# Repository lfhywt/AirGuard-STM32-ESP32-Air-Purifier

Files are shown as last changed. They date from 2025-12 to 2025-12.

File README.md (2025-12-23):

English version: [README_EN.md](README_EN.md)

# AirGuard-STM32-ESP32-Air-Purifier

# AirGuard

**AirGuard** 是一款 **成品级智能空气净化器系统**，集成空气质量检测、风扇控制、本地屏幕交互以及云端 App 远程控制。

本项目从 **硬件设计到软件实现全部由本人独立完成**，包括：

- 原理图设计  
- PCB 设计与打板  
- 元器件焊接  
- 3D 外壳建模（部分）  
- STM32 / ESP32 嵌入式代码开发  
  

   

   

---

## 项目特点

- STM32 + ESP32 **双 MCU 架构**
- 空气质量实时监测  
  - PM2.5 / PM10  
  - VOC  
  - 温湿度  
- 本地串口屏交互（Nextion）
- Blinker App 云端远程控制与状态同步
- 自定义通信协议与状态同步机制
- 3D 打印外壳，完整成品形态  

> 外壳模板参考并感谢原作者：  
> **tatzhao**  
> https://oshwhub.com/tatzhao/smart-colorful-air-purifier-spark-plan

---

## 实现步骤

### 1. PCB 打板

- 根据 Gerber 文件在 **嘉立创** 打板  
- 板子尺寸：**100mm × 40mm**
- 可使用嘉立创的免费打板券

---

### 2. 元器件采购

- 根据 BOM 表购买元器件  
- **务必逐项核对型号与参数**

---

### 3. 焊接注意事项

⚠️ **非常重要**

- **需要去掉 R3 电阻**  
  否则 STM32 无法正常工作
- **需要去掉 CH340**  
  否则会与串口屏冲突，导致屏幕无法正确发送指令

---

### 4. STM32 固件烧录

#### 串口烧录（FLYMCU）

- 使用 **PA9 / PA10**
- BOOT 配置：
  - BOOT0 = 高电平
  - BOOT1 = 低电平（VCC → BOOT0，GND → BOOT1）
- 烧录完成后：
  - BOOT0 = 低电平
  - BOOT1 = 低电平

#### ST-Link 烧录

- BOOT0 = 低电平
- BOOT1 = 低电平
- 已经引出对应 SWD 引脚

---

### 5. ESP32 固件烧录

- 开发环境：**Arduino IDE**
- 目标型号：**ESP32-S3 Dev Module**
- 使用串口烧录：
  - RX ↔ TX
  - TX ↔ RX

#### 下载模式进入方式

1. 按住 **SW1（复位）**
2. 按住 **SW2（IO 拉低）**
3. 松开 SW1
4. 松开 SW2
5. 上传固件
6. 烧录完成后复位

#### 注意事项

- 使用 **Blinker（点灯科技）SDK**
- 通信协议：**MQTT**
- **不建议使用 ESP8266**
- 若 ESP32 内存不足：
  - 在 Arduino IDE 中调整 `Partition Scheme`
  - 建议选择 **App > 1MB**
   

---

### 6. 3D 外壳

- 基于原作者提供的 3D 模型
- 根据自身需求进行二次修改与定制
- 3D 打印后组装成完整成品

---

### 7. 显示屏

- 型号：**淘晶驰 T1 系列 4.3 英寸串口触摸屏**
- 可淘宝购买或自行更换其他型号

⚠️ **注意**

- 使用串口屏时 **不要焊接 CH340**
- 否则会干扰 STM32 与屏幕通信

---

### 8. 风扇

- 型号：**利民 TL-B12W EXTREM 12cm**
- 风量充足，噪音较低，实际使用效果良好

---

### 9. 空气传感器模块

- 使用 **康福尔集成传感器模块**
- 通过串口接收协议帧并解析数据
- 相比自研传感器方案，成本更低、实现更简单

---

## ⚠️ 重要声明

- **本项目无任何防呆保护**
- 接线务必确认正确  
- 错误接线可能导致器件损坏或财产损失  

❗ **本项目仅用于学习与开源交流，严禁商用**

---

## License

本项目遵循开源协议，仅供学习研究使用。

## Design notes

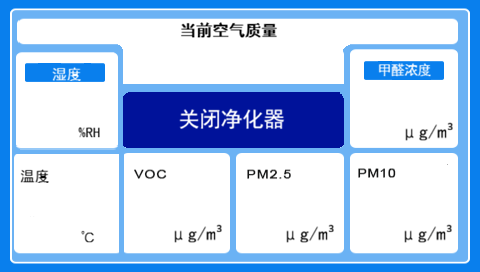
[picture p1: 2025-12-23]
屏幕HMI/关机.png

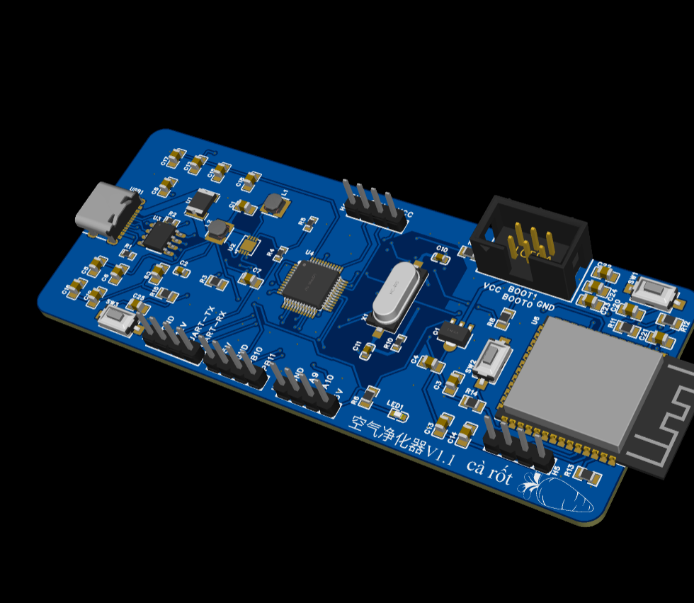
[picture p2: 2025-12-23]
主控板/主控板3D图.png

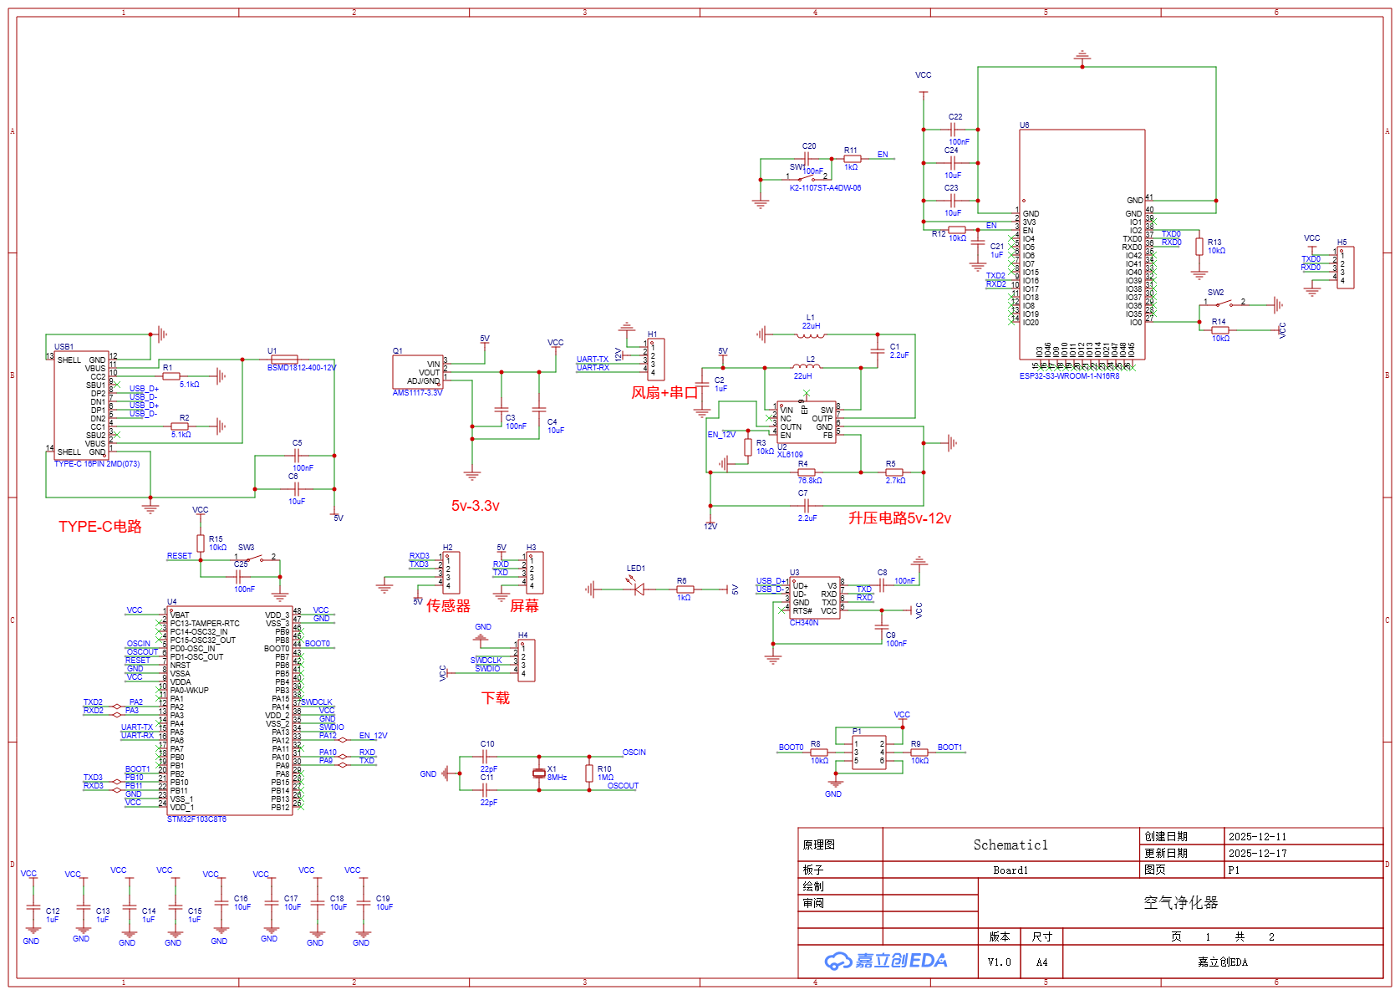
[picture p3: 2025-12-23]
主控板/原理图.png

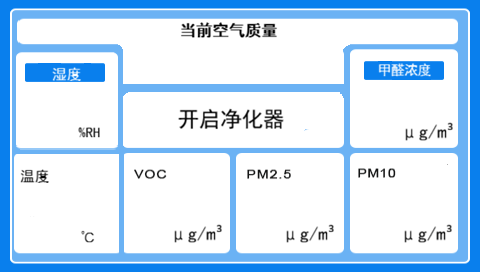
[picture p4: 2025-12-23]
屏幕HMI/开机正常.png

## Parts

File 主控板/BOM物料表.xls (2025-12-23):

立创商城BOM报价单
BOM配单编号：BOM251212004284 |  |  |  |  | 上传时间：2025-12-12 15:18:34 |  |  |  | 1.名称释义：MPQ--最小包装量；MOQ--最小起订量； 2.匹配结果为实时查询结果，库存和价格可能会有波动。如超过24小时，请在立创商城重新匹配后下单； 3.订货商品的价格仅供参考，请提交订单后确定。 4.如有部分物料未能成功匹配，需要整单购买，请联系商城客服。
BOM名称：PCB1_空气净化器 |  |  |  |  | 采购套数：3
商品总价:￥126.19 (原价:￥128.37, 折扣:-￥2.18) 注：报价单总价不含待确认和无法匹配项 |  |  |  |  | 网址：https://bom.szlcsc.com/bom.html
原始需求 |  |  |  |  |  |  |  |  | 匹配结果 |  |  |  |  |  |  | 订单满足
ID | Name Manufacturer Part | Designator | Footprint | Quantity | Manufacturer Part | Manufacturer | Supplier | Supplier Part | 匹配结果 | 商品名称 | 型号 | 品牌 | 封装 | 参数 | 目录 | 商品编号 | 商品链接 | 渠道 | 交期 | MOQ | MPQ | 库存 | 购买数量 | 单价(RMB) | 关税 | 小计(RMB) | 备注
1 | 10uF CL21A106KAYNNNE | C6,C4,C16,C17,C19,C18 | C0805 | 6 | CL21A106KAYNNNE | SAMSUNG(三星) | LCSC | C15850 | 系统匹配 | 10uF ±10% 25V | CL21A106KAYNNNE | SAMSUNG(三星) | 0805 | 容值：10uF 精度：±10% 额定电压：25V 温度系数：X5R | 电容 | C15850 | https://item.szlcsc.com/16532.html | 现货 | 4小时内发货 | 20 | 2000 | 7661920 | 20 | 0.065 | 0
2 | 100nF CL21B104KBCNNNC | C5,C3,C8,C9 | C0805 | 4 | CL21B104KBCNNNC | SAMSUNG(三星) | LCSC | C1711 | 系统匹配 | 100nF ±10% 50V | CL21B104KBCNNNC | SAMSUNG(三星) | 0805 | 容值：100nF 精度：±10% 额定电压：50V 温度系数：X7R | 电容 | C1711 | https://item.szlcsc.com/2063.html | 现货 | 4小时内发货 | 50 | 4000 | 1039600 | 50 | 0.038115 | 0
3 | AMS1117-3.3V AMS1117-3.3V | Q1 | SOT-89-3_L4.5-W2.5-P1.50-LS4.2-BR | 1 | AMS1117-3.3V | MSKSEMI(美森科) | LCSC | C5120796 | 系统匹配 | 输入18V 输出3.3V 1A | AMS1117-3.3V | MSKSEMI(美森科) | SOT-89 | 输出类型：固定 工作电压：15V 输出电压：3.3V 输出电流：1A 输出极性：正极 | 电源管理 | C5120796 | https://item.szlcsc.com/5706251.html | 现货 | 4小时内发货 | 10 | 1000 | 154580 | 10 | 0.255455 | 0
4 | 5.1kΩ 0603WAF5101T5E | R1,R2 | R0603 | 2 | 0603WAF5101T5E | UNI-ROYAL(厚声) | LCSC | C23186 | 系统匹配 | 5.1kΩ ±1% 100mW 厚膜电阻 | 0603WAF5101T5E | UNI-ROYAL(厚声) | 0603 | 电阻类型：厚膜电阻 阻值：5.1kΩ 精度：±1% 功率：100mW 工作电压：75V 温度系数：±100ppm/℃ | 电阻 | C23186 | https://item.szlcsc.com/23913.html | 现货 | 4小时内发货 | 100 | 5000 | 5391900 | 100 | 0.006231 | 0
5 | STM32F103C8T6 STM32F103C8T6 | U4 | LQFP-48_L7.0-W7.0-P0.50-LS9.0-BL | 1 | STM32F103C8T6 | ST(意法半导体) | LCSC | C8734 | 系统匹配 | 主流增强型ARM Cortex-M3 MCU，具有64 KB Flash、72 MHz CPU、电机控制、USB和CAN | STM32F103C8T6 | ST(意法半导体) | LQFP-48(7x7) | CPU内核：ARM Cortex-M3 CPU最大主频：72MHz CPU位数：32 Bit | 单片机/微控制器 | C8734 | https://item.szlcsc.com/9243.html | 现货 | 4小时内发货 | 1 | 250 | 76990 | 3 | 7.42 | 0
6 | TYPE-C 16PIN 2MD(073) TYPE-C 16PIN 2MD(073) | USB1 | USB-C-SMD_TYPE-C-6PIN-2MD-073 | 1 | TYPE-C 16PIN 2MD(073) | SHOU HAN(首韩) | LCSC | C2765186 | 系统匹配 | Type-C 母 卧贴 | TYPE-C 16PIN 2MD(073) | SHOU HAN(首韩) | SMD | 连接器类型：Type-C 公母：母 安装方式：卧贴 触点数量：16P 端口数量：1 额定电流 - 电源：3A 工作温度：-25℃~+85℃ | 连接器 | C2765186 | https://item.szlcsc.com/2901843.html | 现货 | 4小时内发货 | 10 | 1000 | 682210 | 10 | 0.38342 | 0
7 | 2.2uF 0805X225K500NT | C1,C7 | C0805 | 2 | 0805X225K500NT | FH(风华) | LCSC | C108719 | 系统匹配 | 2.2uF ±10% 50V | 0805X225K500NT | FH(风华) | 0805 | 容值：2.2uF 精度：±10% 额定电压：50V 温度系数：X5R | 电容 | C108719 | https://item.szlcsc.com/109938.html | 现货 | 4小时内发货 | 10 | 2000 | 103830 | 10 | 0.1123 | 0
8 | 1uF 0603B105K500NT | C2 | C0603 | 1 | 0603B105K500NT | FH(风华) | LCSC | C90540 | 系统匹配 | 1uF ±10% 50V | 0603B105K500NT | FH(风华) | 0603 | 容值：1uF 精度：±10% 额定电压：50V 温度系数：X7R | 电容 | C90540 | https://item.szlcsc.com/91727.html | 现货 | 4小时内发货 | 20 | 4000 | 1650660 | 20 | 0.0534 | 0
9 | 22pF CL10C220JB8NNNC | C10,C11 | C0603 | 2 | CL10C220JB8NNNC | SAMSUNG(三星) | LCSC | C1653 | 系统匹配 | 22pF ±5% 50V | CL10C220JB8NNNC | SAMSUNG(三星) | 0603 | 容值：22pF 精度：±5% 额定电压：50V 温度系数：C0G | 电容 | C1653 | https://item.szlcsc.com/2005.html | 现货 | 4小时内发货 | 100 | 4000 | 2595400 | 100 | 0.023958 | 0
10 | PZ254V-11-04P PZ254V-11-04P | H1,H2,H4,H3 | HDR-TH_4P-P2.54-V-M | 4 | PZ254V-11-04P | XFCN(兴飞) | LCSC | C2691448 | 系统匹配 | 1x4P 间距:2.54mm 方针 直插 | PZ254V-11-04P | XFCN(兴飞) | 插件,P=2.54mm | 插针结构：1x4P 间距：2.54mm 圆针/方针：方针 安装方式：直插 排数：单排 总PIN位数：4P 额定电流：3A 额定电压：250V 配合针长度：6mm 塑高：2.5mm 端接针长度：3mm 工作温度：-40℃~+105℃ 颜色：黑色 | 连接器 | C2691448 | https://item.szlcsc.com/2801085.html | 现货 | 4小时内发货 | 20 | 1000 | 404920 | 20 | 0.1384 | 0
11 | 22uH YHNR3015-220M | L1,L2 | IND-SMD_L3.0-W3.0 | 2 | YHNR3015-220M | YJYCOIN(益嘉源) | LCSC | C7433100 | 系统匹配 | 22uH ±20% 1A | YHNR3015-220M | YJYCOIN(益嘉源) | SMD,3x3mm | 电感值：22uH 精度：±20% 额定电流：560mA 饱和电流(Isat)：1A 类型：磁胶屏蔽电感 | 电感/线圈/变压器 | C7433100 | https://item.szlcsc.com/8440050.html | 现货 | 4小时内发货 | 50 | 2000 | 1300 | 50 | 0.0565 | 0
12 | 2.54-2*3P简牛 2.54-2*3P简牛 | P1 | IDC-TH_6P-P2.54_C11214 | 1 | 2.54-2*3P简牛 | BOOMELE(博穆精密) | LCSC | C11214 | 系统匹配 | 2.54mm 2x3P 排数:2 每排P数:3 | 2.54-2*3P简牛 | BOOMELE(博穆精密) | 插件,P=2.54mm | 连接器类型：简牛座 间距：2.54mm 结构：2x3P 额定电流：1A 安装方式：直插 行距：2.54mm 排数：2 每排PIN数：3 触头材质：黄铜 触头镀层：金 工作温度：-55℃~+105℃ | 连接器 | C11214 | https://item.szlcsc.com/11763.html | 现货 | 4小时内发货 | 5 | 380 | 7555 | 5 | 0.5423 | 0
13 | 76.8kΩ RS-03K7682FT | R4 | R0603 | 1 | RS-03K7682FT | FH(风华) | LCSC | C321997 | 系统匹配 | 厚膜电阻 76.8kΩ ±1% 100mW | RS-03K7682FT | FH(风华) | 0603 | 电阻类型：厚膜电阻 阻值：76.8kΩ 精度：±1% 功率：100mW 工作电压：50V 温度系数：±100ppm/℃ | 电阻 | C321997 | https://item.szlcsc.com/302902.html | 现货 | 4小时内发货 | 100 | 5000 | 2900 | 100 | 0.0033 | 0
14 | 2.7kΩ RS-03K2701FT | R5 | R0603 | 1 | RS-03K2701FT | FH(风华) | LCSC | C118394 | 系统匹配 | 厚膜电阻 2.7kΩ ±1% 100mW | RS-03K2701FT | FH(风华) | 0603 | 电阻类型：厚膜电阻 阻值：2.7kΩ 精度：±1% 功率：100mW 工作电压：50V 温度系数：±100ppm/℃ | 电阻 | C118394 | https://item.szlcsc.com/119659.html | 现货 | 4小时内发货 | 100 | 5000 | 14600 | 100 | 0.0083 | 0
15 | 10kΩ 0805W8F1002T5E | R8,R9,R3 | R0805 | 3 | 0805W8F1002T5E | UNI-ROYAL(厚声) | LCSC | C17414 | 系统匹配 | 10kΩ ±1% 125mW 厚膜电阻 | 0805W8F1002T5E | UNI-ROYAL(厚声) | 0805 | 电阻类型：厚膜电阻 阻值：10kΩ 精度：±1% 功率：125mW 工作电压：150V 温度系数：±100ppm/℃ | 电阻 | C17414 | https://item.szlcsc.com/18102.html | 现货 | 4小时内发货 | 100 | 5000 | 23805300 | 100 | 0.01083 | 0
16 | 1MΩ 0603WAF1004T5E | R10 | R0603 | 1 | 0603WAF1004T5E | UNI-ROYAL(厚声) | LCSC | C22935 | 系统匹配 | 1MΩ ±1% 100mW 厚膜电阻 | 0603WAF1004T5E | UNI-ROYAL(厚声) | 0603 | 电阻类型：厚膜电阻 阻值：1MΩ 精度：±1% 功率：100mW 工作电压：75V 温度系数：±100ppm/℃ | 电阻 | C22935 | https://item.szlcsc.com/23662.html | 现货 | 4小时内发货 | 100 | 5000 | 4846800 | 100 | 0.006231 | 0
17 | XL6109 XL6109 | U2 | DFN-8_L3.0-W3.0-P0.50-TL-EP2.1 | 1 | XL6109 | XLSEMI(芯龙) | LCSC | C48031577 | 系统匹配 | 600mA 1.2MHz 36V 内置 SBD 的升压型 DC-DC 转换器 | XL6109 | XLSEMI(芯龙) | PDFN-8L(3x3) | 功能类型：升压型 工作电压：2.5V~25V 输出电压：3V~32V 输出电流：600mA 输出类型：可调 | 电源管理 | C48031577 | https://item.szlcsc.com/50274438.html | 现货 | 4小时内发货 | 5 | 5000 | 695 | 5 | 1.4639 | 0
18 | CH340N CH340N | U3 | SOP-8_L4.9-W3.9-P1.27-LS6.0-BL | 1 | CH340N | WCH(南京沁恒) | LCSC | C2977777 | 系统匹配 | USB2.0芯片CH340 | CH340N | WCH(南京沁恒) | SOP-8 | 应用功能：USB转串口 USB协议版本：USB 2.0 通道数：1 数据速率：2Mbps | 通信接口芯片 | C2977777 | https://item.szlcsc.com/3390257.html | 现货 | 4小时内发货 | 1 | 4000 | 7993 | 3 | 3.4 | 0
19 | 8MHz C08000J060 | X1 | HC-49S_L11.4-W4.8 | 1 | C08000J060 | ECEC(东晶) | LCSC | C259040 | 系统匹配 | 8MHz ±20ppm 20pF | C08000J060 | ECEC(东晶) | HC-49S-SMD | 晶振类型：贴片晶振 频率：8MHz 常温频差：±20ppm 负载电容：20pF | 振荡器/谐振器 | C259040 | https://item.szlcsc.com/251590.html | 现货 | 4小时内发货 | 5 | 1000 | 36900 | 5 | 0.5647 | 0
20 | GL0603UG01 GL0603UG01 | LED1 | LED0603-RD | 1 | GL0603UG01 | Guiguang light(桂光光电) | LCSC | C51933293 | 系统匹配 | 0603 翠绿 高亮 | GL0603UG01 | Guiguang light(桂光光电) | 0603 | 发光颜色：翠绿色 正向压降(Vf)：3.2V 正向电流：20mA 波长：510nm~531nm 二极管配置：独立二极管 透镜颜色：无色透明透镜 发光强度：358mcd 发光角度：120° 载带方式：正贴 工作温度：-40℃~+85℃ | 光电器件 | C51933293 | https://item.szlcsc.com/54645989.html | 现货 | 4小时内发货 | 50 | 4000 | 386900 | 50 | 0.02176 | 0
21 | 1kΩ 0805W8F1001T5E | R6 | R0805 | 1 | 0805W8F1001T5E | UNI-ROYAL(厚声) | LCSC | C17513 | 系统匹配 | 1kΩ ±1% 125mW 厚膜电阻 | 0805W8F1001T5E | UNI-ROYAL(厚声) | 0805 | 电阻类型：厚膜电阻 阻值：1kΩ 精度：±1% 功率：125mW 工作电压：150V 温度系数：±100ppm/℃ | 电阻 | C17513 | https://item.szlcsc.com/18201.html | 现货 | 4小时内发货 | 100 | 5000 | 8833500 | 100 | 0.010416 | 0
22 | 1uF CL21B105KBFNNNE | C12,C13,C14,C15 | C0805 | 4 | CL21B105KBFNNNE | SAMSUNG(三星) | LCSC | C28323 | 系统匹配 | 1uF ±10% 50V | CL21B105KBFNNNE | SAMSUNG(三星) | 0805 | 容值：1uF 精度：±10% 额定电压：50V 温度系数：X7R | 电容 | C28323 | https://item.szlcsc.com/29074.html | 现货 | 4小时内发货 | 20 | 2000 | 5965920 | 20 | 0.058707 | 0
23 | BSMD1812-400-12V BSMD1812-400-12V | U1 | F1812 | 1 | BSMD1812-400-12V | BHFUSE(佰宏) | LCSC | C18164540 | 系统匹配 | 12V 4A 1812自恢复 | BSMD1812-400-12V | BHFUSE(佰宏) | 1812 | 耐压(Vmax)：12V 最大电流(Imax)：40A 保持电流(Ihold)：4A 跳闸电流(Itrip)：8A | TVS/保险丝/板级保护 | C18164540 | https://item.szlcsc.com/19305879.html | 现货 | 4小时内发货 | 5 | 1500 | 7100 | 5 | 0.8253 | 0
24 | 4.7kΩ 0805W8F4701T5E | R7 | R0805 | 1 | 0805W8F4701T5E | UNI-ROYAL(厚声) | LCSC | C17673 | 系统匹配 | 4.7kΩ ±1% 125mW 厚膜电阻 | 0805W8F4701T5E | UNI-ROYAL(厚声) | 0805 | 电阻类型：厚膜电阻 阻值：4.7kΩ 精度：±1% 功率：125mW 工作电压：150V 温度系数：±100ppm/℃ | 电阻 | C17673 | https://item.szlcsc.com/18361.html | 现货 | 4小时内发货 | 100 | 5000 | 3764100 | 100 | 0.010323 | 0
25 | 2.4GHz ESP-01S | U5 | WIFIM-TH_8P-L24.7-W14.4-P2.54 | 1 | ESP-01S | Ai-Thinker(安信可) | LCSC | C503582 | 系统匹配 | 完整的802.11b/g/nWi-FiSoC模块 | ESP-01S | Ai-Thinker(安信可) | - | 核心芯片：ESP8266芯片 频率：2.4GHz 发射功率：16dBm 接收灵敏度：-90dBm | 物联网/通信模块 | C503582 | https://item.szlcsc.com/516229.html | 现货 | 4小时内发货 | 1 | 200 | 383 | 3 | 16.78 | 0

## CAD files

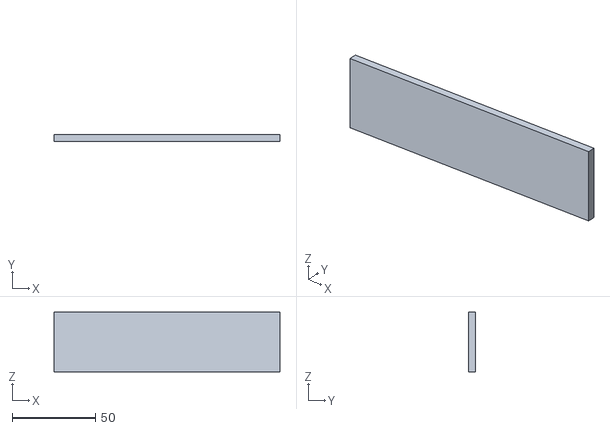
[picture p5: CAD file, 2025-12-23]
3D外壳/kongjingnew4.STL
135.6 x 3.90 x 35.8

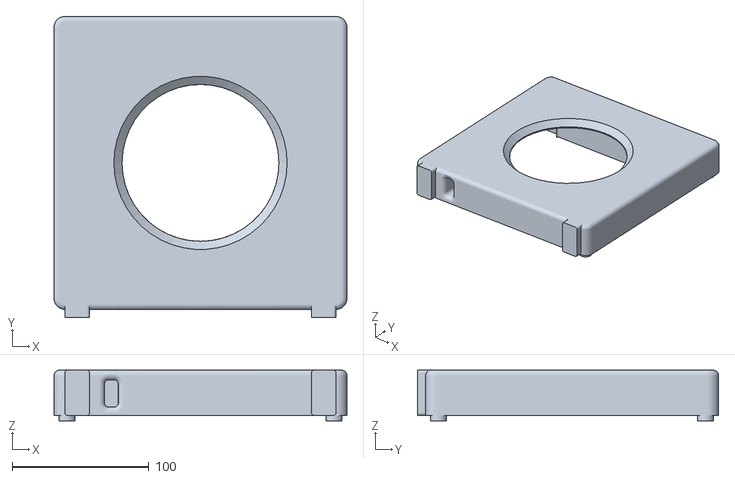
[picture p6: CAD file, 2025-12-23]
3D外壳/kongjingnew3.STL
214.0 x 220.0 x 37.0

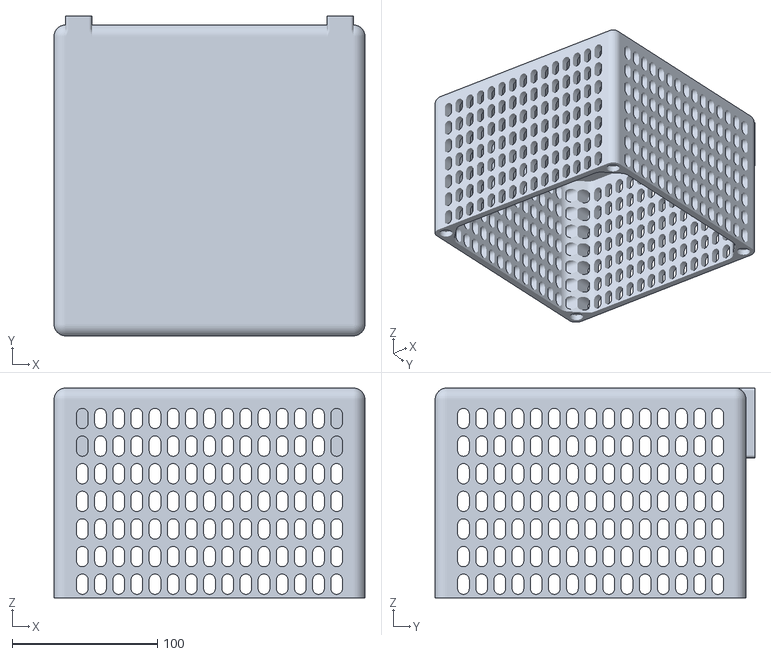
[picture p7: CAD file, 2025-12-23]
3D外壳/kongjingnew1.STL
214.0 x 220.0 x 144.5

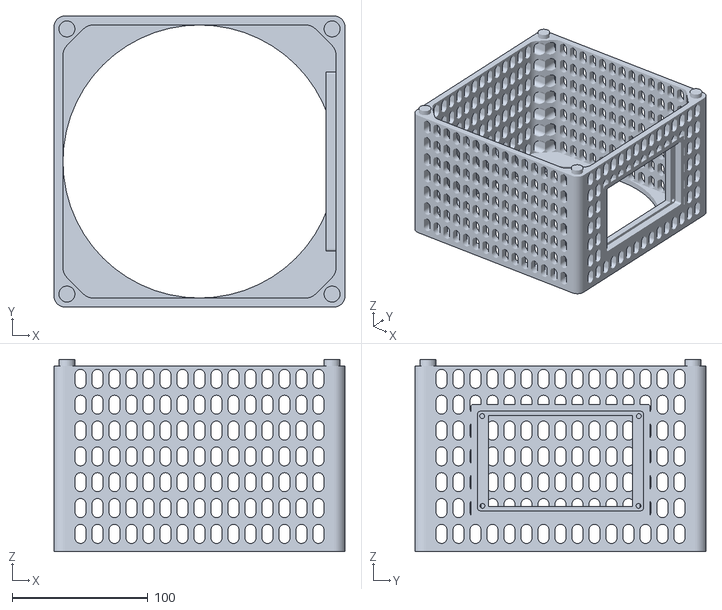
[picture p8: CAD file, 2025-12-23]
3D外壳/kongjingnew2new2.STL
214.0 x 214.0 x 141.3

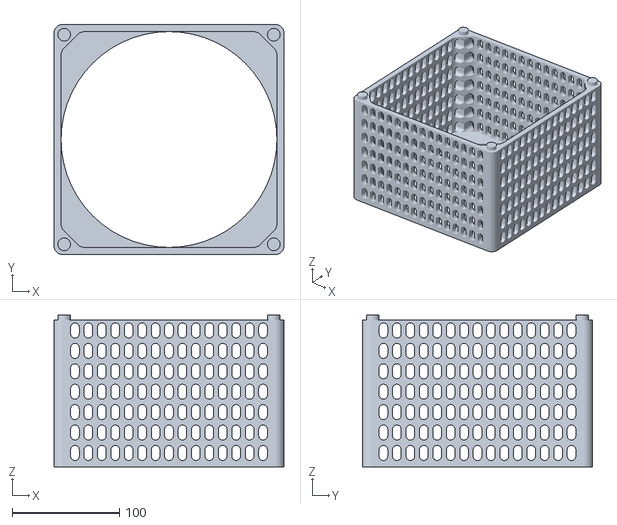
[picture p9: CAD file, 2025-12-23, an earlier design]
3D外壳/kongjingnew2(旧).STL
214.0 x 214.0 x 141.3

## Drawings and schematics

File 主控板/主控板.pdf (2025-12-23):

# GND CLK IOVCC

C10

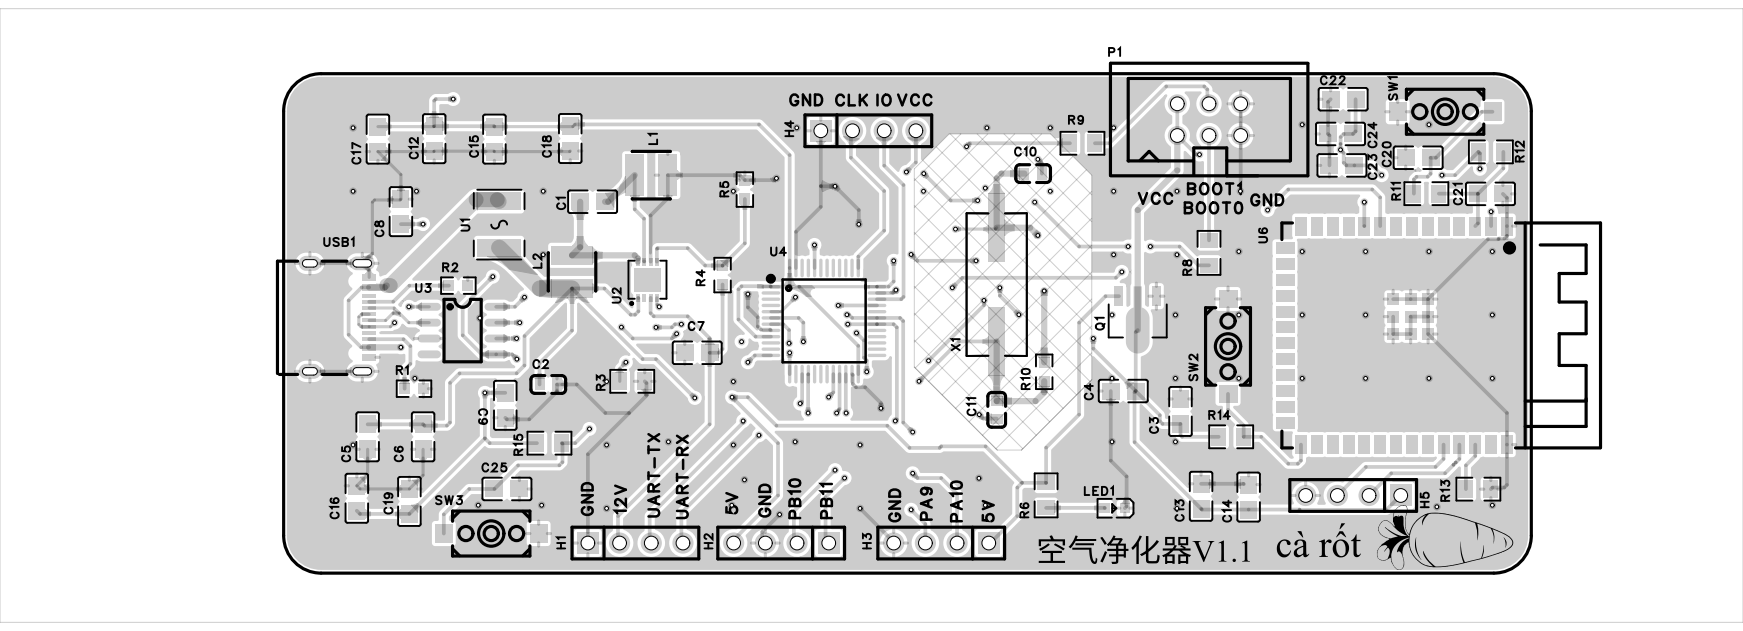
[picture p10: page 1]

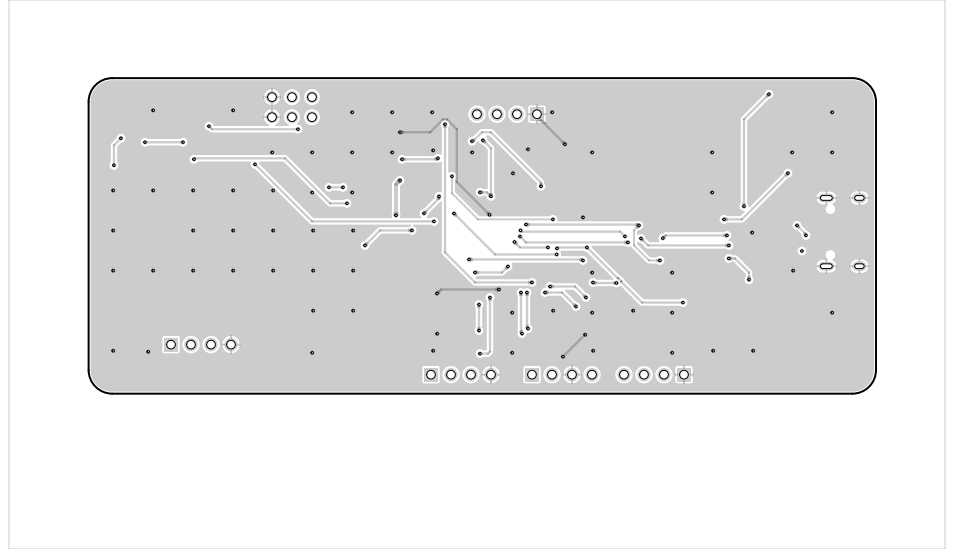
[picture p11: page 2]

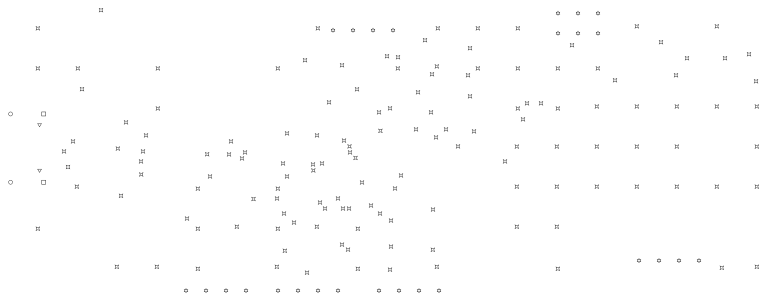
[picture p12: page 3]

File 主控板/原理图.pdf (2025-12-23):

IO0 27 IO35 28 IO36 29 IO37 30 IO38 31 IO39 32 IO40 33 IO41 34 IO42 35 RXD0 36 TXD0 37 IO2 38 IO1 39 GND 40

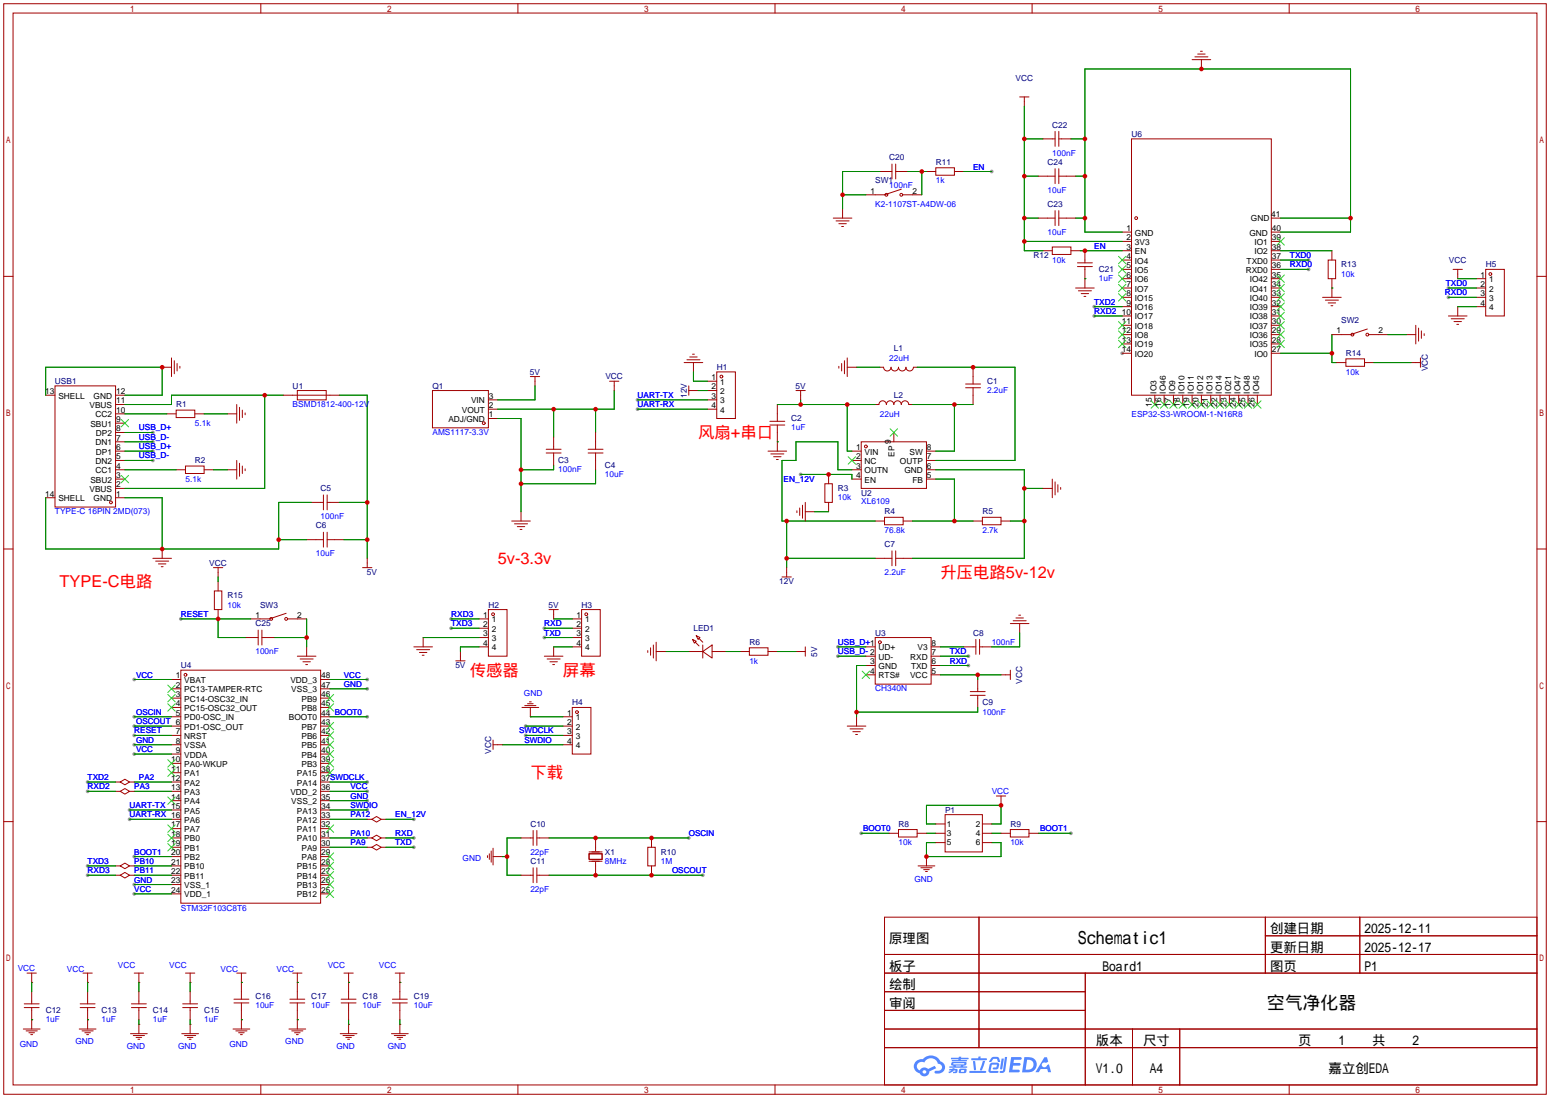
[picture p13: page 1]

原理图 | Schematic1 | 创建日期 | 2025-12-11

更新日期 | 2025-12-17

板子 | Board1 | 图页 | P1
绘制 | | 空气净化器
审阅

V1.0 | A4 | 嘉立创EDA

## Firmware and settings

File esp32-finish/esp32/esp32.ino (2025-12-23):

#define BLINKER_PRINT Serial
#define BLINKER_WIFI
#include <Blinker.h>

/* ================= Blinker 配置 ================= */
char auth[] = "5caa4c9bdcb2";
char ssid[] = "wifi";
char pswd[] = "1234567890";

/* ================= Blinker 组件 ================= */
BlinkerButton ButtonFan("btn-abc");
BlinkerNumber NumFan("num-fan");
BlinkerNumber NumTemp("num-temp");
BlinkerNumber NumHumi("num-humi");
BlinkerNumber NumPM25("num-pm25");
BlinkerNumber NumPM10("num-pm10");
BlinkerNumber NumVOC("num-voc");
BlinkerNumber NumJQ("num-jq");
BlinkerNumber NumScore("num-score");

/* ================= STM32 串口 ================= */
#define STM32_SERIAL Serial1
#define STM32_RX_PIN 16
#define STM32_TX_PIN 17

/* ================= 风扇状态 ================= */
// STM32 权威状态
static uint8_t fanState = 0;      // 0=OFF, 1=ON

// APP 操作中的 pending 状态
static bool    fanWaitingAck = false;
static uint8_t fanPendingState = 0;
static unsigned long fanAckTimer = 0;
static uint8_t fanRetryCnt = 0;

#define FAN_ACK_TIMEOUT_MS 2000
#define FAN_RETRY_MAX      2

/* ================= 空气数据结构 ================= */
#pragma pack(1)
typedef struct {
  uint16_t pm25;
  uint16_t pm10;
  uint16_t voc;
  uint16_t jq;
  int16_t  temp_x10;
  uint16_t humi_x10;
  uint8_t  score;
} AIR_DATA_T;
#pragma pack()

/* =================================================
 * ESP32 → STM32：发送风扇命令
 * ================================================= */
void sendFanCmd(uint8_t on)
{
  uint8_t buf[4] = {0x33, on ? 0x01 : 0x00, 0x0D, 0x0A};
  STM32_SERIAL.write(buf, 4);
}

/* =================================================
 * Blinker 按钮回调（APP）
 * ================================================= */
void fanBtnCallback(const String &state)
{
  BLINKER_LOG("APP click:", state);

  if (state == BLINKER_CMD_ON) {
    fanPendingState = 1;
  } else if (state == BLINKER_CMD_OFF) {
    fanPendingState = 0;
  } else {
    return;
  }

  fanWaitingAck = true;
  fanRetryCnt = 0;
  fanAckTimer = millis();

  // 立刻显示 pending（乐观 UI）
  ButtonFan.print(fanPendingState ? "on" : "off");
  NumFan.print(fanPendingState);

  sendFanCmd(fanPendingState);
}

/* =================================================
 * STM32 → ESP32：风扇状态帧解析（权威）
 * ================================================= */
void onFanStateFromSTM32(uint8_t state)
{
  fanState = state ? 1 : 0;

  fanWaitingAck = false;
  fanRetryCnt = 0;

  // ★ 权威状态刷新 UI
  ButtonFan.print(fanState ? "on" : "off");
  NumFan.print(fanState);

  BLINKER_LOG("STM32 fan state:", fanState);
}

/* =================================================
 * STM32 → ESP32：空气数据解析
 * ================================================= */
void onAirData(uint8_t *buf)
{
  AIR_DATA_T air;
  memcpy(&air, buf, sizeof(AIR_DATA_T));

  NumPM25.print(air.pm25);
  NumPM10.print(air.pm10);
  NumVOC.print(air.voc);
  NumJQ.print(air.jq);
  NumTemp.print(air.temp_x10 / 10.0);
  NumHumi.print(air.humi_x10 / 10.0);
  NumScore.print(air.score);
}

/* =================================================
 * STM32 串口协议解析
 * ================================================= */
void parseSTM32Serial()
{
  static uint8_t step = 0;
  static uint8_t len = 0;
  static uint8_t buf[64];
  static uint8_t idx = 0;

  while (STM32_SERIAL.available()) {
    uint8_t c = STM32_SERIAL.read();

    switch (step) {
      case 0:
        if (c == 0x33) step = 1;
        else if (c == 0xAA) step = 10;
        break;

      // ===== 风扇帧 33 xx 0D 0A =====
      case 1:
        buf[0] = c;
        step = 2;
        break;
      case 2:
        step = (c == 0x0D) ? 3 : 0;
        break;
      case 3:
        if (c == 0x0A) onFanStateFromSTM32(buf[0]);
        step = 0;
        break;

      // ===== 空气帧 =====
      case 10:
        step = (c == 0x02) ? 11 : 0;
        break;
      case 11:
        len = c;
        idx = 0;
        step = 12;
        break;
      case 12:
        buf[idx++] = c;
        if (idx >= len) step = 13;
        break;
      case 13:
        step = (c == 0x00) ? 14 : 0;
        break;
      case 14:
        step = (c == 0x0D) ? 15 : 0;
        break;
      case 15:
        if (c == 0x0A) onAirData(buf);
        step = 0;
        break;
    }
  }
}

/* =================================================
 * Blinker 心跳（只显示，不做决策）
 * ================================================= */
void heartbeat()
{
  if (fanWaitingAck) {
    ButtonFan.print(fanPendingState ? "on" : "off");
    NumFan.print(fanPendingState);
  } else {
    ButtonFan.print(fanState ? "on" : "off");
    NumFan.print(fanState);
  }
}

/* =================================================
 * setup / loop
 * ================================================= */
void setup()
{
  Serial.begin(115200);
  STM32_SERIAL.begin(115200, SERIAL_8N1, STM32_RX_PIN, STM32_TX_PIN);

  Blinker.begin(auth, ssid, pswd);

  ButtonFan.attach(fanBtnCallback);
  Blinker.attachHeartbeat(heartbeat);

  BLINKER_LOG("ESP32 Fan System Ready");
}

void loop()
{
  Blinker.run();
  parseSTM32Serial();

  // ACK 超时处理
  if (fanWaitingAck) {
    if (millis() - fanAckTimer > FAN_ACK_TIMEOUT_MS) {
      if (fanRetryCnt < FAN_RETRY_MAX) {
        fanRetryCnt++;
        fanAckTimer = millis();
        sendFanCmd(fanPendingState);
        BLINKER_LOG("Resend fan cmd:", fanRetryCnt);
      } else {
        fanWaitingAck = false;
        // 回滚显示权威状态
        ButtonFan.print(fanState ? "on" : "off");
        NumFan.print(fanState);
        BLINKER_LOG("ACK failed, rollback");
      }
    }
  }

  delay(1);
}

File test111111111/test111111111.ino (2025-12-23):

#define BLINKER_PRINT Serial
#define BLINKER_WIFI
#include <Blinker.h>

/* ===== Blinker 配置 ===== */
char auth[] = "5caa4c9bdcb2";
char ssid[] = "wifi";
char pswd[] = "1234567890";

/* ===== Blinker 组件 ===== */
BlinkerButton Button1("btn-abc");
BlinkerNumber NumFan("num-fan");
BlinkerNumber NumTemp("num-temp");
BlinkerNumber NumHumi("num-humi");
BlinkerNumber NumPM25("num-pm25");
BlinkerNumber NumPM10("num-pm10");
BlinkerNumber NumVOC("num-voc");
BlinkerNumber NumJQ("num-jq");
BlinkerNumber NumScore("num-score");

/* ===== STM32 串口 ===== */
#define STM32_SERIAL Serial1
#define STM32_RX_PIN 16
#define STM32_TX_PIN 17

/* ===== 风扇状态 ===== */
static uint8_t fanState = 0;  // 0=OFF, 1=ON

/* ===== 空气数据结构 ===== */
#pragma pack(1)
typedef struct
{
  uint16_t pm25;
  uint16_t pm10;
  uint16_t voc;
  uint16_t jq;
  int16_t temp_x10;
  uint16_t humi_x10;
  uint8_t score;
} AIR_DATA_T;
#pragma pack()

/* =========================================================
 * STM32 ← ESP32：发送风扇控制帧
 * 33 xx 0D 0A
 * ========================================================= */
void sendFanCmdToSTM32(uint8_t on) {
  uint8_t buf[4] = {
    0x33,
    on ? 0x01 : 0x00,
    0x0D,
    0x0A
  };

  STM32_SERIAL.write(buf, 4);
}

/* =========================================================
 * Blinker 按钮回调（★关键）
 * ========================================================= */
void button1_callback(const String &state) {
  BLINKER_LOG("APP Fan Button:", state);

  if (state == BLINKER_CMD_ON) {
    fanState = 1;

    Button1.print("on");   // ★ 立刻更新 APP
    NumFan.print(1);

    sendFanCmdToSTM32(1);
  }
  else if (state == BLINKER_CMD_OFF) {
    fanState = 0;

    Button1.print("off");  // ★ 立刻更新 APP
    NumFan.print(0);

    sendFanCmdToSTM32(0);
  }
}



/* =========================================================
 * STM32 → ESP32：风扇状态解析
 * ========================================================= */
void parseFanFrame(uint8_t state) {
  if (state == 0x01) {
    fanState = 1;              // ★ 必须同步真实状态
    Button1.print("on");
    NumFan.print(1);
  } else {
    fanState = 0;              // ★ 必须同步真实状态
    Button1.print("off");
    NumFan.print(0);
  }
}

/* =========================================================
 * STM32 → ESP32：空气数据解析
 * ========================================================= */
void parseAirFrame(uint8_t *data) {
  AIR_DATA_T air;
  memcpy(&air, data, sizeof(AIR_DATA_T));

  NumPM25.print(air.pm25);
  NumPM10.print(air.pm10);
  NumVOC.print(air.voc);
  NumJQ.print(air.jq);
  NumTemp.print(air.temp_x10 / 10.0);
  NumHumi.print(air.humi_x10 / 10.0);
  NumScore.print(air.score);
}

/* =========================================================
 * 串口状态机
 * ========================================================= */
void parseSTM32Serial() {
  static uint8_t state = 0;
  static uint8_t len = 0;
  static uint8_t buf[32];
  static uint8_t idx = 0;

  while (STM32_SERIAL.available()) {
    uint8_t c = STM32_SERIAL.read();

    switch (state) {
      case 0:
        if (c == 0x33) state = 10;
        else if (c == 0xAA) state = 1;
        break;

        /* ===== 风扇帧：33 xx 0D 0A ===== */
      case 10:       // 收到 0x33
        buf[0] = 0;  // 清空
        state = 11;
        break;

      case 11:       // 收 状态字节
        buf[0] = c;  // 0x00 / 0x01
        state = 12;
        break;

      case 12:  // 等 0x0D
        if (c == 0x0D) state = 13;
        else state = 0;
        break;

      case 13:  // 等 0x0A
        if (c == 0x0A) {
          parseFanFrame(buf[0]);
        }
        state = 0;
        break;


      /* ===== 空气帧 ===== */
      case 1:
        if (c == 0x02) state = 2;
        else state = 0;
        break;
      case 2:
        len = c;
        idx = 0;
        state = 3;
        break;
      case 3:
        buf[idx++] = c;
        if (idx >= len) state = 4;
        break;
      case 4:
        if (c == 0x00) state = 5;
        else state = 0;
        break;
      case 5:
        if (c == 0x0D) state = 6;
        else state = 0;
        break;
      case 6:
        if (c == 0x0A) parseAirFrame(buf);
        state = 0;
        break;
    }
  }
}


/* =========================================================
 * Blinker 心跳：同步 APP 按钮状态（★缺的就是这个）
 * ========================================================= */
void heartbeat() {
  BLINKER_LOG("heartbeat, fanState:", fanState);

  if (fanState) {
    Button1.print("on");
  } else {
    Button1.print("off");
  }
}

/* ========================================================= */

void setup() {
  Serial.begin(115200);
  STM32_SERIAL.begin(115200, SERIAL_8N1, STM32_RX_PIN, STM32_TX_PIN);

  pinMode(LED_BUILTIN, OUTPUT);
  digitalWrite(LED_BUILTIN, HIGH);

  Blinker.begin(auth, ssid, pswd);

  Button1.attach(button1_callback);  // ★ 必须有
  Blinker.attachHeartbeat(heartbeat);

  BLINKER_LOG("ESP32-S3 Air + Fan Ready");
}

void loop() {
  Blinker.run();
  parseSTM32Serial();
}
